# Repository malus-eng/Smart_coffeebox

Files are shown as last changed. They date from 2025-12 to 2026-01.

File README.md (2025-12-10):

# Smart Coffee Box 

An Arduino-based smart storage box for coffee beans and tea leaves.  
It monitors temperature, humidity and TVOC, and automatically controls a fan, OLED display and buzzer to protect flavour during storage.

> Hardware prototype built with an Arduino MKR WAN 1310, DHT22, SGP30, limit switch, 40×40 mm fan, 0.96" OLED and a piezo buzzer inside a 3D-printed PLA enclosure.

---

## Features

- **Environmental monitoring**
  - DHT22 for temperature and relative humidity inside the box  
  - SGP30 for TVOC, the total volatile organic compounds in the air  
  - Limit switch to detect whether the lid is closed  

- **Automatic fan control**
  - Turns on when humidity or temperature are too high  
  - Uses hysteresis so the fan does not flicker on and off all the time  
  - Runs in duty cycles, for example 60 seconds on and 180 seconds off, to balance drying and aroma preservation  
  - Only runs when the lid is closed  

- **User feedback**
  - 0.96" I²C OLED shows  
    - Temperature in °C and humidity in %RH  
    - TVOC in ppb  
    - Fan status, on or off  
    - A simple three-level freshness indicator based on TVOC  
    - A blinking warning message when the box is too dry  

- **Lid-open warning**
  - If the lid is left open for more than 60 seconds, a piezo buzzer starts a periodic beep pattern to remind the user to close the box  

---

## Hardware

**Microcontroller**

- Arduino MKR WAN 1310  

**Sensors**

- DHT22 for temperature and humidity  
- SGP30 for TVOC  
- Limit switch for lid open or closed detection  

**Actuators and user interface**

- 40×40 mm DC fan driven by an IRLZ44N MOSFET and a 1N4001 flyback diode  
- 0.96" I²C OLED display based on an SSD1306 controller, 128×64 pixels  
- PKM22EPP-40 piezo buzzer driven from an IO pin through a series resistor of about 100 Ω  

**Enclosure**

- 3D-printed PLA box  
- Dedicated desiccant compartment on or near the lid  
- Cut-out for the fan and an air flow path across the desiccant  
- Mounting points for sensors and the limit switch  

More details about wiring and mechanical design can live in:

- `hardware/wiring.md`  
- `hardware/enclosure-notes.md`  

---

## Wiring – summary

**MKR WAN 1310 to modules**

- **DHT22**  
  - VCC → 3V3  
  - GND → GND  
  - DATA → D2  

- **Limit switch**  
  - One side → GND  
  - Other side → D3, configured as `INPUT_PULLUP`  

- **SGP30 over I²C**  
  - VCC → 3V3  
  - GND → GND  
  - SDA → A4, SDA line  
  - SCL → A5, SCL line  

- **0.96" OLED, SSD1306 over I²C**  
  - VCC → 3V3  
  - GND → GND  
  - SDA → A4, shared with SGP30  
  - SCL → A5, shared with SGP30  

- **Fan with MOSFET driver**  
  - Fan positive → 5V  
  - Fan negative → MOSFET drain, the middle pin of the IRLZ44N  
  - MOSFET source → GND  
  - MOSFET gate → D5 through a resistor of about 220 Ω  
  - 1N4001 diode for flyback  
    - Diode band side → fan positive, 5V  
    - Other side → fan negative and MOSFET drain  

- **Buzzer, PKM22EPP-40**  
  - Buzzer positive → D6 through a resistor of about 100 Ω  
  - Buzzer negative → GND  

All grounds must be common, including MKR ground, fan ground, sensors and buzzer.

---

## Firmware

The main Arduino sketch lives in:

```text
SmartCoffeeBox.ino

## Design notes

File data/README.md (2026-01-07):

# Sample Data and Runtime Evidence

This folder contains sample runtime data and photos captured from the Smart Coffee Box during operation.  
These files demonstrate real sensor readings and system behaviour.

## Included Files

### 1. Sensor Log (simulated runtime)
- `sensor_log_2026-01-05.txt`  
  Continuous readings collected every 5 minutes over a 3-hour period.
  Includes:
  - Temperature (°C)
  - Humidity (%RH)
  - TVOC (ppb)

This file provides evidence of long-term stability and measurement trends.

### 2. OLED Display Photos
- `oled_freshly_stored.jpg`  
  Display reading shortly after placing fresh coffee beans in the enclosure.
- `oled_after_storage_period.jpg`  
  Display reading after beans have remained in storage for a period of time.

These images illustrate how temperature, humidity and TVOC levels vary over time while the system is running.

---

More logged data, charts or additional photos may be added as testing continues.

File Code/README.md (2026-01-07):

# Smart Coffee Box Firmware

This folder contains the Arduino firmware that runs the Smart Coffee Box system.  
The program monitors temperature, humidity, lid status, and volatile organic compounds (TVOCs),
and automatically manages air circulation and alerts to maintain coffee storage quality.

---

## Features

- Reads:
  - **Temperature & Humidity** using DHT22
  - **TVOC** using SGP30
  - **Lid open/closed** via limit switch
- Drives:
  - **Cooling/air circulation fan** via MOSFET
  - **Piezo buzzer** for lid left-open warning
- Displays live status on a **0.96" SSD1306 OLED**
- Includes:
  - Hysteresis logic for humidity + temperature
  - Duty-cycle fan control to preserve aroma
  - Automatic lid detection lockout (fan disabled when open)
  - Delayed buzzer alarm after 60+ seconds lid-open
  - Dryness warning blink if humidity is too low

---

## Required Libraries

Install these through **Arduino Library Manager**:

| Library | Used For |
|---|---|
| Adafruit SGP30 | TVOC readings |
| DHT sensor library | Humidity and temperature |
| Adafruit SSD1306 | OLED control |
| Adafruit GFX | OLED graphics |
| Wire (built-in) | I2C communications |

Search by name in:  
**Sketch → Include Library → Manage Libraries…**

---

## Hardware Compatibility

Designed for:
- Arduino **MKR WAN 1310** (3.3 V logic)

Compatible with:
- Arduino Nano / Uno (if pin mapping updated to 5 V logic)
- ESP32 (with minor pin edits)

---

## Pin Mapping (Summary)

| Signal | MCU Pin |
|---|---|
| DHT22 DATA | D2 |
| Limit Switch | D3 |
| Fan MOSFET Gate | D5 |
| Buzzer | D6 |
| SGP30 SDA / OLED SDA | 11 (I2C) |
| SGP30 SCL / OLED SCL | 12 (I2C) |

Full pin map available in `/hardware/pinmap.md`

---

## How It Works — Core Logic

### 1. Sensor Reading
- DHT22 → Temperature + Humidity
- SGP30 → TVOC (Indoor Air Quality)
- Limit switch → Detects lid state

### 2. Trigger Decisions
- Humidity + temperature thresholds include hysteresis
- If lid is **closed** and readings exceed limits → fan requested
- If lid is **open** → fan always disabled

### 3. Fan Control with Duty Cycle
- When triggered:
  - **ON 60 sec**
  - **OFF 180 sec**
- Extends moisture retention & aroma

### 4. Lid Warning System
- If lid remains open for **>60 sec**:
  - Buzzer beeps ON/OFF (200/800 ms pattern)
- Resets instantly when lid closes

### 5. Display Output
- Temperature / Humidity
- TVOC
- Fan status
- Freshness suggestion (based on TVOC)
- Dryness warning (if <35% RH)

---

## Adjustable Parameters
Edit these constants to tune behavior:

```cpp
HUM_ON_THRESHOLD
HUM_OFF_THRESHOLD
HUM_TOO_DRY_THRESHOLD
TEMP_ON_THRESHOLD
TEMP_OFF_THRESHOLD
FAN_ON_TIME_MS
FAN_OFF_TIME_MS
LID_OPEN_WARNING_DELAY_MS
BUZZER_ON_MS
BUZZER_OFF_MS

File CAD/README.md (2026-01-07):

# 3D Printed Enclosure Parts

This folder contains the 3D printable components for the device enclosure.  
All files are provided in **.STL format** and are ready to be imported into a slicing tool.

## Included Parts

| File name | Description |
|---|---|
| `box_base.stl` | Main enclosure body, supports and houses all electronics |
| `box_separator.stl`  | Internal divider separating the sensor chamber, coffee bean storage compartment, and electronics area |
| `box_lid.stl` | Top lid with a recessed slot designed to hold a desiccant pack |

---

## Recommended Print Settings

The following parameters are suggested based on successful test prints:

- **Material:** PLA or PETG  
- **Layer height:** 0.2 mm  
- **Top/Bottom layers:** 4  
- **Walls / Perimeters:** 3  
- **Infill:** 15–20% (Grid or Gyroid recommended)  
- **Supports:** Enable automatic supports  
- **Bed adhesion:** Brim recommended if parts lift  
- **Nozzle diameter:** 0.4 mm

---

## Assembly Notes

- The separator slots into the base; for stability, applying cyanoacrylate (502 glue) at the joints is recommended.
- The lid is friction-fit and can be removed easily.
- Remove all support material after printing and ensure no ventilation slots are blocked, as airflow is critical for fan operation.
- Sensors should be placed away from direct airflow from the fan.
- Wire routing should allow the lid to open without disconnecting components.

---

## CAD Format and Modifications

If you would like to modify the enclosure:

- The parts were designed in **Fusion 360**
- Dimensions are aligned to:
  - Arduino MKR WAN 1310 footprint
  - 40×40×10 mm DC fan
  - Breadboard and wiring clearance

Feel free to modify and re-export as needed.

---

## Recommended Print Orientation

| Part | Print Orientation |
|---|---|
| Base | Flat, bottom face down |
| Divider  | Laid flat on print bed |
| Lid | Flat, top surface down |

Printing in these orientations helps ensure:

- Minimal support usage
- Stronger layer adhesion
- Reliable fit and tolerances

---

## License

All enclosure files are released under the same **MIT License** as the project code.  
You are free to print, modify, and redistribute these models.

---

Happy printing! 🛠️

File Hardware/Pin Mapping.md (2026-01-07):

# Pin Mapping

## Microcontroller

- Board: Arduino MKR WAN 1310  
- Logic voltage: 3.3 V  
- I2C bus (MKR WAN 1310): SDA = pin 11, SCL = pin 12  
- Note: The schematic is drawn with an Arduino Nano as a logical equivalent MCU.  
  The functional mapping to the MKR WAN 1310 is as listed below.

## MCU Connection Table

| Component | Pin / Signal | MCU Pin / Rail | Notes |
| --- | --- | --- | --- |
| **DHT22** | VCC | 3.3 V | Power |
| DHT22 | GND | GND | Ground (common) |
| DHT22 | DATA | D2 | Temperature & humidity data |
| **Limit Switch**  | One side | GND | Connected to ground |
| Limit Switch | Other side (signal) | D3 | Digital input, configured as INPUT_PULLUP  |
| **Fan MOSFET** | Gate (via 220 Ω resistor) | D5 | PWM / on–off control for DC fan |
| **Buzzer** | Positive (via 100 Ω resistor) | D6 | Digital output for beeps / alerts |
| Buzzer | Negative | GND | Return path |
| **SGP30** | VCC | 3.3 V | Power |
| SGP30 | GND | GND | Ground (common) |
| SGP30 | SDA | 11 (SDA) | I2C data line |
| SGP30 | SCL | 12 (SCL) | I2C clock line |
| **OLED SSD1306**  | VCC | 3.3 V | Power |
| OLED SSD1306 | GND | GND | Ground (common) |
| OLED SSD1306 | SDA | 11 (SDA) | I2C data line (shared with SGP30) |
| OLED SSD1306 | SCL | 12 (SCL) | I2C clock line (shared with SGP30) |
| **Power rails** | 3.3 V rail | — | Feeds MCU, DHT22, SGP30, OLED |
| Power rails | 5 V rail | — | Feeds DC fan positive terminal |
| Power rails | GND rail | — | All grounds connected together |

## Discrete Components and High-Current Path

These connections are **between components**, not directly to MCU pins, but are important for reproducing the circuit:

- **MOSFET (IRLZ44N, viewed from front with pins down)**  
  - Left pin  → Gate (from MCU D5 through ~220 Ω resistor)  
  - Middle pin → Drain (to Fan negative terminal)  
  - Right pin → Source (to GND)

- **Fan (40×40×10 mm, 5 V DC brushless)**  
  - Fan +  → 5 V supply  
  - Fan −  → MOSFET Drain  

- **Flyback diode (1N4001)**  
  - Cathode (banded side) → Fan + (5 V side)  
  - Anode                → Fan − / MOSFET Drain  

- **Gate resistor (~220 Ω)**  
  - One side → MCU D5  
  - Other side → MOSFET Gate  

- **Buzzer series resistor (~100 Ω)**  
  - One side → MCU D6  
  - Other side → Buzzer positive terminal  

- **Grounding**  
  - MCU GND, DHT22 GND, SGP30 GND, OLED GND, MOSFET Source,  
    Buzzer negative terminal, and Fan negative (through MOSFET)  
    are all tied to the same common GND rail.

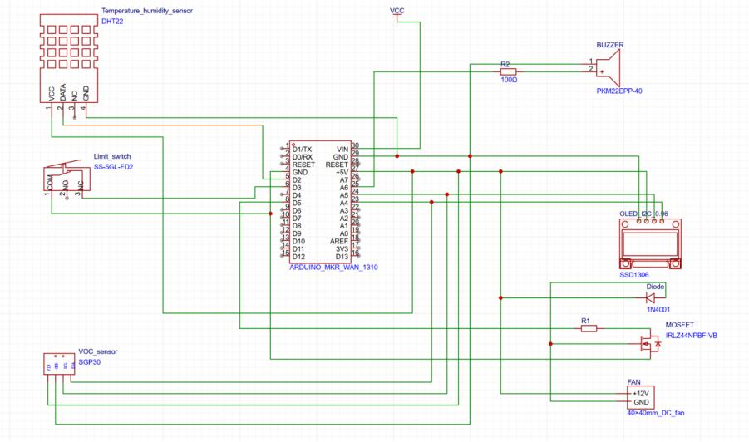
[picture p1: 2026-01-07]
Hardware/Schematic_SmartBox.png

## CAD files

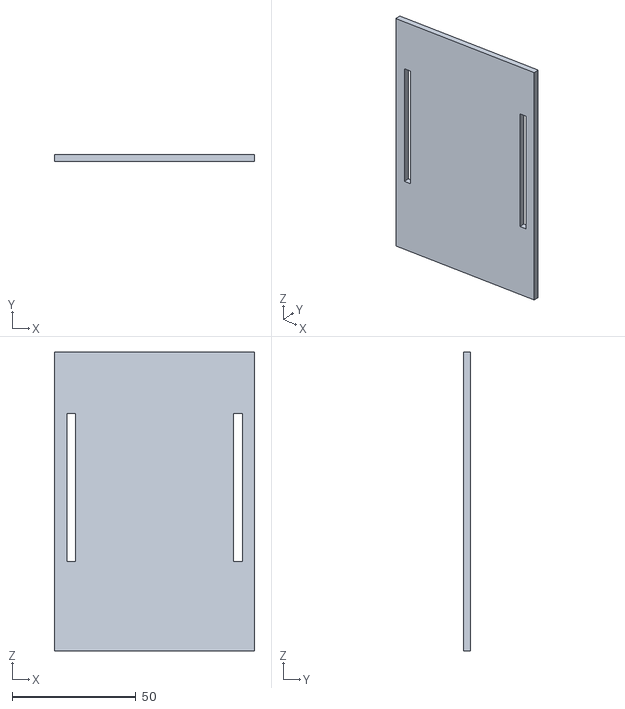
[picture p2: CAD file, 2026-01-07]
CAD/divider.stl
81.0 x 3.00 x 121.0

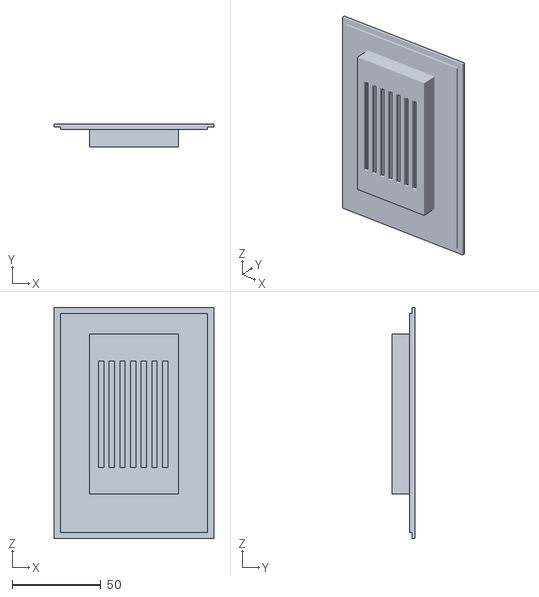
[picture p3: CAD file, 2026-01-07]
CAD/Lid.stl
90.0 x 13.0 x 130.0

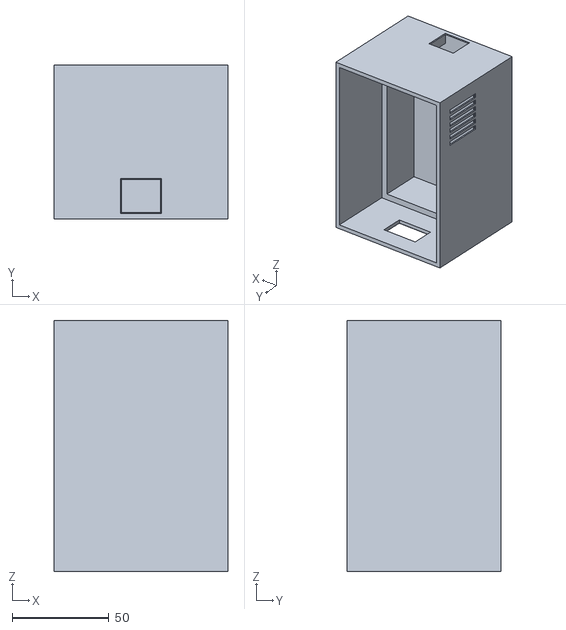
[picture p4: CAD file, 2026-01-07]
CAD/box.stl
90.0 x 80.0 x 130.0

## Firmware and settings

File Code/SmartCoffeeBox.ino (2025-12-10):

#include <Wire.h>
#include <Adafruit_SGP30.h>
#include <DHT.h>
#include <Adafruit_GFX.h>
#include <Adafruit_SSD1306.h>

// ---------------------- Pin configuration ----------------------
const int FAN_PIN           = 5;   // MOSFET gate (through resistor)
const int LIMIT_SWITCH_PIN  = 3;   // Lid switch: one side to GND, other to this pin
const int DHT_PIN           = 2;   // DHT22 data pin
const int BUZZER_PIN        = 6;   // PKM22EPP-40 buzzer (+ via 100R)

// ---------------------- Sensor types ---------------------------
#define DHTTYPE DHT22

// ---------------------- OLED configuration ---------------------
#define SCREEN_WIDTH  128
#define SCREEN_HEIGHT 64
#define OLED_RESET    -1  // No dedicated reset pin

// ---------------------- Thresholds -----------------------------
const float HUM_ON_THRESHOLD      = 65.0f;  // RH%: turn humidity trigger ON
const float HUM_OFF_THRESHOLD     = 60.0f;  // RH%: turn humidity trigger OFF (hysteresis)
const float HUM_TOO_DRY_THRESHOLD = 35.0f;  // RH%: show dryness warning

const float TEMP_ON_THRESHOLD     = 28.0f;  // deg C: turn temperature trigger ON
const float TEMP_OFF_THRESHOLD    = 26.0f;  // deg C: turn temperature trigger OFF

// Fan duty cycle to preserve aroma
const unsigned long FAN_ON_TIME_MS  = 60000UL;   // 60 seconds ON
const unsigned long FAN_OFF_TIME_MS = 180000UL;  // 180 seconds OFF

// Lid open warning timing
const unsigned long LID_OPEN_WARNING_DELAY_MS = 60000UL; // Start beeping after 60 seconds
const unsigned long BUZZER_ON_MS             = 200UL;    // 200 ms beep ON
const unsigned long BUZZER_OFF_MS            = 800UL;    // 800 ms beep OFF

// Timing configuration
const unsigned long SENSOR_INTERVAL_MS  = 2000UL;  // Sensor read interval
const unsigned long DISPLAY_INTERVAL_MS = 500UL;   // Display update interval
const unsigned long BLINK_INTERVAL_MS   = 500UL;   // Dryness warning blink interval

// ---------------------- Global objects -------------------------
DHT dht(DHT_PIN, DHTTYPE);
Adafruit_SGP30 sgp;
Adafruit_SSD1306 display(SCREEN_WIDTH, SCREEN_HEIGHT, &Wire, OLED_RESET);

// ---------------------- Global state variables -----------------
float gTemperature = NAN;
float gHumidity    = NAN;
uint16_t gTVOC     = 0;

bool dhtOK = false;
bool sgpOK = false;

bool gLidClosed = false;

// Triggers with hysteresis
bool humidityTriggerActive = false;
bool tempTriggerActive     = false;

// Fan control state
bool fanDemand     = false; // Environment wants fan activity
bool lastFanDemand = false;
bool fanIsOn       = false;
unsigned long fanStateChangeTime = 0;

// Timing helpers
unsigned long lastSensorTime  = 0;
unsigned long lastDisplayTime = 0;
unsigned long lastBlinkTime   = 0;

// Dryness warning blink state
bool drynessWarningVisible = false;

// Lid open warning / buzzer state
bool previousLidClosed      = true;
unsigned long lidOpenStartTime     = 0;
bool lidWarningActive       = false;
bool buzzerOn               = false;
unsigned long buzzerStateChangeTime = 0;

// ---------------------- Helper: compute freshness text ---------
const char* getFreshnessText(uint16_t tvoc, bool valid) {
  if (!valid) {
    return "Freshness: unknown";
  }

  // Simple absolute thresholds in ppb.
  // You can tune these later based on real data.
  if (tvoc >= 250) {
    return "Freshness: HIGH - use now";
  } else if (tvoc >= 80) {
    return "Freshness: MEDIUM";
  } else {
    return "Freshness: LOW - not ideal";
  }
}

// ---------------------- Helper: read sensors -------------------
void readSensors() {
  // Lid switch: HIGH means lid is closed (based on your wiring)
  gLidClosed = (digitalRead(LIMIT_SWITCH_PIN) == HIGH);

  // DHT22
  float h = dht.readHumidity();
  float t = dht.readTemperature(); // Celsius

  if (isnan(h) || isnan(t)) {
    dhtOK = false;
  } else {
    dhtOK = true;
    gHumidity = h;
    gTemperature = t;
  }

  // SGP30
  if (sgp.IAQmeasure()) {
    sgpOK = true;
    gTVOC = sgp.TVOC;
  } else {
    sgpOK = false;
  }

  // Serial debug (no CO2 printed)
  Serial.println("----- Sensor Reading -----");
  if (dhtOK) {
    Serial.print("Temperature: ");
    Serial.print(gTemperature);
    Serial.println(" C");

    Serial.print("Humidity   : ");
    Serial.print(gHumidity);
    Serial.println(" %");
  } else {
    Serial.println("DHT22 error");
  }

  if (sgpOK) {
    Serial.print("TVOC: ");
    Serial.print(gTVOC);
    Serial.println(" ppb");
  } else {
    Serial.println("SGP30 error");
  }

  Serial.print("Lid closed: ");
  Serial.println(gLidClosed ? "YES" : "NO");
  Serial.println("--------------------------");
  Serial.println();
}

// ---------------------- Helper: update triggers ----------------
void updateTriggers() {
  // Humidity trigger with hysteresis
  if (!dhtOK) {
    humidityTriggerActive = false;
  } else {
    if (gHumidity >= HUM_ON_THRESHOLD) {
      humidityTriggerActive = true;
    } else if (gHumidity <= HUM_OFF_THRESHOLD) {
      humidityTriggerActive = false;
    }
  }

  // Temperature trigger with hysteresis
  if (!dhtOK) {
    tempTriggerActive = false;
  } else {
    if (gTemperature >= TEMP_ON_THRESHOLD) {
      tempTriggerActive = true;
    } else if (gTemperature <= TEMP_OFF_THRESHOLD) {
      tempTriggerActive = false;
    }
  }

  // Fan demand: environment wants some air circulation
  fanDemand = (humidityTriggerActive || tempTriggerActive);

  // Safety: do not run fan when lid is open
  if (!gLidClosed) {
    fanDemand = false;
  }
}

// ---------------------- Helper: update fan state ---------------
void updateFanState(unsigned long now) {
  if (!fanDemand) {
    // No demand: force fan OFF
    fanIsOn = false;
    digitalWrite(FAN_PIN, LOW);
    lastFanDemand = false;
    return;
  }

  if (!lastFanDemand) {
    // Demand just turned from false to true: start a new duty cycle
    fanIsOn = true;
    fanStateChangeTime = now;
    digitalWrite(FAN_PIN, HIGH);
    lastFanDemand = true;
    return;
  }

  // Demand is still true: run duty cycle (ON for FAN_ON_TIME_MS, OFF for FAN_OFF_TIME_MS)
  if (fanIsOn) {
    if (now - fanStateChangeTime >= FAN_ON_TIME_MS) {
      fanIsOn = false;
      fanStateChangeTime = now;
      digitalWrite(FAN_PIN, LOW);
    }
  } else {
    if (now - fanStateChangeTime >= FAN_OFF_TIME_MS) {
      fanIsOn = true;
      fanStateChangeTime = now;
      digitalWrite(FAN_PIN, HIGH);
    }
  }
}

// ---------------------- Helper: update lid warning & buzzer ----
void updateLidWarningAndBuzzer(unsigned long now) {
  // When lid is closed, reset timer and stop buzzer
  if (gLidClosed) {
    lidWarningActive = false;
    lidOpenStartTime = now;

    if (buzzerOn) {
      noTone(BUZZER_PIN);
      buzzerOn = false;
    }

    previousLidClosed = true;
    return;
  }

  // Lid is open
  if (previousLidClosed) {
    // Lid has just been opened
    lidOpenStartTime = now;
    lidWarningActive = false;

    if (buzzerOn) {
      noTone(BUZZER_PIN);
      buzzerOn = false;
    }
  }

  // Check if lid has been open long enough to trigger warning
  if (!lidWarningActive && (now - lidOpenStartTime >= LID_OPEN_WARNING_DELAY_MS)) {
    lidWarningActive = true;
    buzzerOn = false;
    buzzerStateChangeTime = now;
  }

  // If warning is active, run a simple beep pattern (ON/OFF)
  if (lidWarningActive) {
    if (buzzerOn) {
      // Currently ON: turn it OFF after BUZZER_ON_MS
      if (now - buzzerStateChangeTime >= BUZZER_ON_MS) {
        noTone(BUZZER_PIN);
        buzzerOn = false;
        buzzerStateChangeTime = now;
      }
    } else {
      // Currently OFF: turn it ON after BUZZER_OFF_MS
      if (now - buzzerStateChangeTime >= BUZZER_OFF_MS) {
        tone(BUZZER_PIN, 4000); // Around 4 kHz for PKM22EPP-40
        buzzerOn = true;
        buzzerStateChangeTime = now;
      }
    }
  }

  previousLidClosed = false;
}

// ---------------------- Helper: update OLED display ------------
void updateDisplay(unsigned long now) {
  (void)now; // unused for now, kept for future use

  display.clearDisplay();
  display.setTextSize(1);
  display.setTextColor(SSD1306_WHITE);
  display.setCursor(0, 0);

  display.println("Smart Coffee Box");

  // Temperature and humidity line
  if (dhtOK) {
    display.print("T: ");
    display.print(gTemperature, 1);
    display.print("C  H: ");
    display.print(gHumidity, 1);
    display.println("%");
  } else {
    display.println("DHT22: error");
  }

  // TVOC line only
  if (sgpOK) {
    display.print("TVOC: ");
    display.print(gTVOC);
    display.println(" ppb");
  } else {
    display.println("TVOC: error");
  }

  // Fan status
  display.print("Fan: ");
  display.println(fanIsOn ? "ON" : "OFF");

  // Freshness indicator
  const char* freshness = getFreshnessText(gTVOC, sgpOK);
  display.println(freshness);

  // Bottom area: dryness warning (blinking)
  if (dhtOK && gHumidity < HUM_TOO_DRY_THRESHOLD) {
    if (drynessWarningVisible) {
      display.setCursor(0, 48); // lower half of the screen
      display.println("Too dry! Use less desiccant!");
    }
  }

  display.display();
}

// ---------------------- Arduino setup -------------------------
void setup() {
  Serial.begin(115200);
  while (!Serial) {
    ; // Wait for serial on some boards
  }

  Serial.println();
  Serial.println("=== Smart Coffee Box ===");

  pinMode(FAN_PIN, OUTPUT);
  digitalWrite(FAN_PIN, LOW);

  pinMode(LIMIT_SWITCH_PIN, INPUT_PULLUP); // One side of switch to GND

  pinMode(BUZZER_PIN, OUTPUT);
  digitalWrite(BUZZER_PIN, LOW);
  noTone(BUZZER_PIN);

  dht.begin();

  Wire.begin();

  if (!display.begin(SSD1306_SWITCHCAPVCC, 0x3C)) {
    Serial.println("OLED init failed");
    while (1) {
      delay(1000);
    }
  }

  display.clearDisplay();
  display.setTextSize(1);
  display.setTextColor(SSD1306_WHITE);
  display.setCursor(0, 0);
  display.println("Smart Coffee Box");
  display.println("Initializing...");
  display.display();

  if (!sgp.begin()) {
    Serial.println("SGP30 init failed");
    display.println("SGP30 error");
    display.display();
    while (1) {
      delay(1000);
    }
  }

  if (!sgp.IAQinit()) {
    Serial.println("SGP30 IAQinit failed");
  } else {
    Serial.println("SGP30 initialized");
  }

  unsigned long now = millis();
  lastSensorTime       = now;
  lastDisplayTime      = now;
  lastBlinkTime        = now;
  fanStateChangeTime   = now;
  lidOpenStartTime     = now;
  buzzerStateChangeTime = now;
}

// ---------------------- Arduino loop --------------------------
void loop() {
  unsigned long now = millis();

  // Periodic sensor readings
  if (now - lastSensorTime >= SENSOR_INTERVAL_MS) {
    lastSensorTime = now;
    readSensors();
    updateTriggers();
  }

  // Fan control based on triggers and duty cycle
  updateFanState(now);

  // Lid warning and buzzer control
  updateLidWarningAndBuzzer(now);

  // Blink state for dryness warning
  if (now - lastBlinkTime >= BLINK_INTERVAL_MS) {
    lastBlinkTime = now;
    drynessWarningVisible = !drynessWarningVisible;
  }

  // Periodic OLED update
  if (now - lastDisplayTime >= DISPLAY_INTERVAL_MS) {
    lastDisplayTime = now;
    updateDisplay(now);
  }
}

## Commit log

2025-12-10 Revise README with project details and specifications
    Updated project description and added detailed features, hardware specifications, wiring summary, and firmware location.
2025-12-10 Add SmartCoffeeBox firmware with sensor integration
2025-12-10 Fix path to main Arduino sketch in README
2026-01-07 Add SmartCoffeeBox Arduino code
2026-01-07 Add pin mapping documentation for hardware setup
2026-01-07 Rename Pin Mapping to Pin Mapping.md
2026-01-07 Revise pin mapping for MKR WAN 1310
    Updated pin mapping details for Arduino MKR WAN 1310, including connection tables for various components and discrete components.
2026-01-07 Enhance CAD documentation and print settings
    Updated descriptions for clarity and added print orientation recommendations.
2026-01-07 Add documentation for Smart Coffee Box firmware
    This document outlines the Smart Coffee Box firmware, detailing features, required libraries, hardware compatibility, pin mapping, core logic, and adjustable parameters.
2026-01-07 Add sensor log for January 5, 2026
    Added sensor data for temperature, humidity, and TVOC readings.
2026-01-07 Update README with sample data and runtime evidence
    Added detailed information about sample data and runtime evidence, including sensor logs and OLED display photos.
